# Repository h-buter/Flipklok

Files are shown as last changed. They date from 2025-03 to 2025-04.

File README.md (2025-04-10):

# Flipklok in 1970s Style with DCF77 Time Synchronization

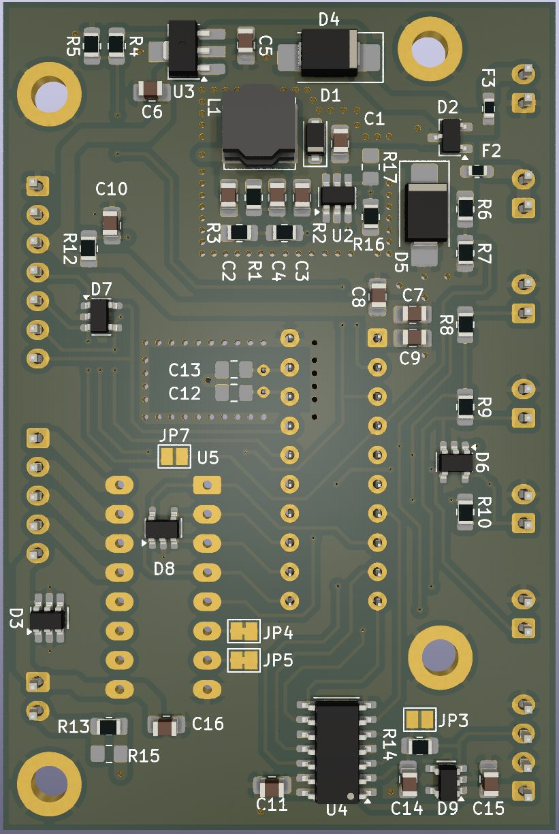
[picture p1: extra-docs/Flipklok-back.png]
back
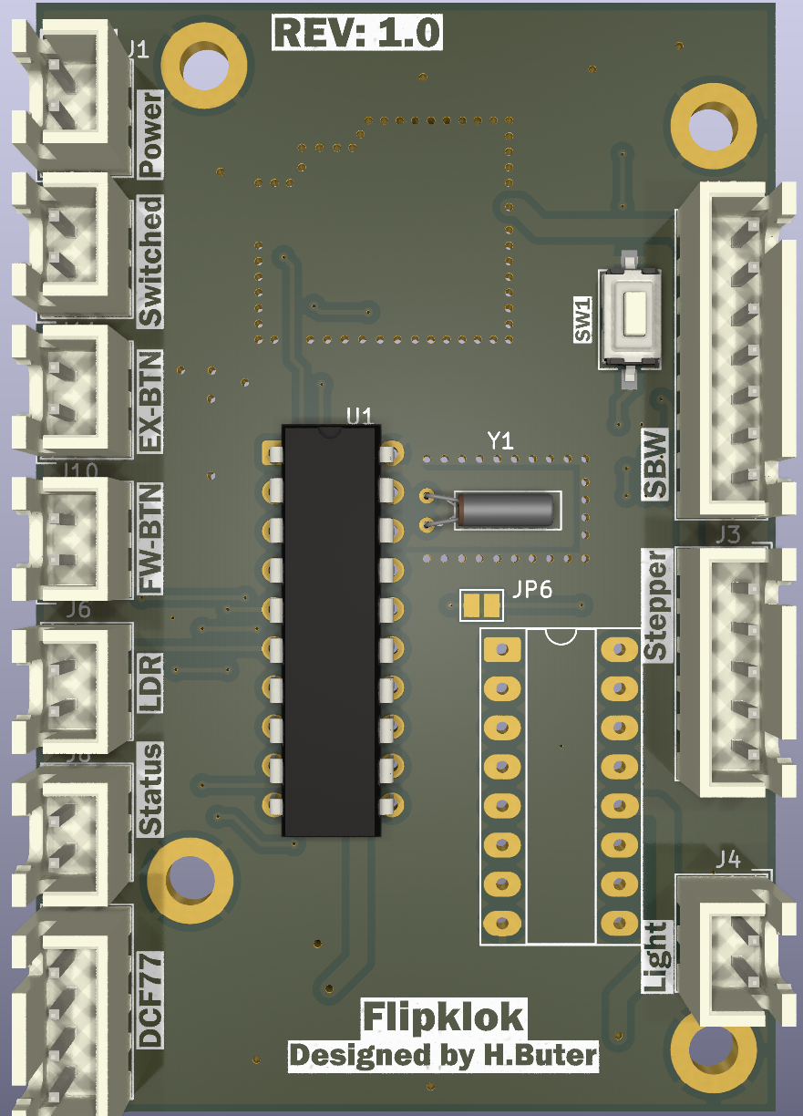
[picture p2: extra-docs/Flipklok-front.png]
front
|  |  |
|---|---|
| | |

Welcome to the repository for my project as part of my Bachelor's degree in Electronics at Windesheim. This
project involves creating a flip clock inspired by the design from the 1970s, which is synchronized using time
information from the DCF77 long-wave time signal. The goal is to ensure that this electronic and electromechanical
device operates efficiently within a low power environment.

At time of writing I am still deciding on if the clock will be used a desk clock or if I build it in to my 1977 Relaint Robin MK1
This is why some design decisions, like low power, are not always directly clear in the scope of a normal clock project.

For the complete documentation see the doxygen documentation hosted on GitHub pages:
- Index: https://h-buter.github.io/Flipklok/index.html
- Start of code: https://h-buter.github.io/Flipklok/main_8c.html 
- Interactive Bill of materials: https://h-buter.github.io/Flipklok/md_extra-docs_2bom.html

## Project Overview

This flip clock project integrates both mechanical components and electronics to display the current time
accurately based on data received from the DCF77 transmitter located in Germany. Designed with energy efficiency
in mind, the clock maintains continuous time tracking to compensate for any potential reception limitations of the
DCF77 signal while minimizing power consumption.

## Key Challenges

- **Mechanical and Time Management**: The project requires careful application of mechanics and efficient time
management techniques to ensure the device functions optimally on a 12V source.

- **Integration of Electronics and Electromechanics**: Incorporating electronic components like motors and sensors
for position detection into the mechanical design poses significant challenges.

- **PCB Design**: The creation of a custom PCB is necessary to accommodate all electronic components while
maintaining compactness and efficiency.

- **DCF77 Protocol Implementation**: Applying the DCF77 protocol ensures accurate time synchronization. This
involves handling signals and data correctly within the system’s constraints.

- **Software Development**: The software component, developed in C with some sections written in assembly
language, is responsible for processing DCF77 data and controlling stepper or servo motors to operate the flip
clock.

## Project Boundaries

### Software
The software aspect focuses on:
- Processing DCF77 signal data.
- Controlling a stepper/servo motor mechanism to display time changes accurately.

### Hardware
The hardware component involves:
- Integrating electronic and electromechanical components for seamless operation of the flip clock module.
- Receiving and processing DCF77 timing information effectively.

## Getting Started

To get started with this project, you need to:

- Code: 
    - If you want to view the code use the doxygen documentation (see intoduction) or view the source files on GitHub.
    - If you want to run the code, install TI code composer studio and clone this repository.
        - This repo should contain every file to be able to compile the code for the MSP430G2553
- PCB:
    - View the PCB files use the exported pdf: [exported pdf's](https://github.com/h-buter/Flipklok/tree/main/PCB/Flipklok/export)
    - Edit the PCB files, Kicad and clone the repo.
    - Run a production:
        - Download the gerber ZIP and give this to you're favorite PCB manufacturer, it may be possible the etch the board you're self but be warned this is not easy because of the multilayer construction.
        - Order the bom
        - Wait for everything to arrive 
        - Assemble
        - Test, don't let the make smoke out (not optional)
            - First power up test
            - Flash the code, i used a launchpad devboard see page 8 till 10 [link to datasheet of launchpad](https://www.ti.com/lit/ug/slau772a/slau772a.pdf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)
- Mechanics:
    - To view the 3d files you can use the free viewing program [Edrawings](https://www.edrawingsviewer.com/download-edrawings)
    - To edit the files you will need Solidworks

## Contribution

Contributions are welcome! Whether it's optimizing the code for better performance or suggesting improvements in
hardware integration, your input is valuable.

## License

This project is licensed under to be determined 

---

Thank you for exploring this unique blend of vintage design and electronics. Should you have any questions
or suggestions regarding this project, feel free to open an issue or contact me directly.

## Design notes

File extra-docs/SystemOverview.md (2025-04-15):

# System overview

This is the originally system overview where the schematic and PCB are based on:
System Overview

[Link to PDF version](SystemOverview.pdf)

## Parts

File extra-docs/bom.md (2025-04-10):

# Bill of materials

See link for an interactive BOM of the PCB:  
[Interactive BOM](https://h-buter.github.io/Flipklok/bom/Flipklok-1.0)

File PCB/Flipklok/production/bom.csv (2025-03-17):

Designator | Footprint | Quantity | Value | LCSC Part #
C1 | 0805 | 1 | 4.7uF 25V X5R
C10 | 0805 | 1 | 1nF
C11, C15, C16, C9 | 0805 | 4 | 0.1uF
C14 | 0805 | 1 | C
C2 | 0805 | 1 | 10uF 16V X5R
C3 | 0805 | 1 | 0,22uF
C4 | 0805 | 1 | 100pF
C5 | 0805 | 1 | 1uF 25V X7R
C6 | 0805 | 1 | 2.2uF 10V X7R
C7 | 0805 | 1 | 10uF
C8 | 0805 | 1 | 1uF
D1 | D_SOD-123F | 1 | PMEG3010ER 30V, 1A
D2 | TSOT-23 | 1 | ESDCAN01-2BLY
D3 | SOT-23-6_Handsoldering | 1 | ESDA19SC6
D4, D5 | D_SMB_Handsoldering | 2 | S2A 50V 1.5A
D6, D7, D8, D9 | SOT-23-5 | 4 | ESDA5V3SC5
F2, F3 | 0603 | 2 | Fuse
J1 | JST_XH_B2B-XH-A_1x02_P2.50mm_Vertical | 1 | Power
J10 | JST_XH_B2B-XH-A_1x02_P2.50mm_Vertical | 1 | FW-btn
J11 | JST_XH_B2B-XH-A_1x02_P2.50mm_Vertical | 1 | EX-btn
J12 | JST_XH_B7B-XH-A_1x07_P2.50mm_Vertical | 1 | Programheader
J2 | JST_XH_B2B-XH-A_1x02_P2.50mm_Vertical | 1 | SW
J3 | JST_XH_B5B-XH-A_1x05_P2.50mm_Vertical | 1 | 28BYJ-48
J4 | JST_XH_B2B-XH-A_1x02_P2.50mm_Vertical | 1 | Backlight
J5 | JST_XH_B4B-XH-A_1x04_P2.50mm_Vertical | 1 | DCF77
J6 | JST_XH_B2B-XH-A_1x02_P2.50mm_Vertical | 1 | LDR
J8 | JST_XH_B2B-XH-A_1x02_P2.50mm_Vertical | 1 | Indicator
L1 | L_Bourns_SRN6045TA | 1 | SRN6045HA
R1 | 0805 | 1 | 82k
R10, R16, R8, R9 | 0805 | 4 | 10k
R12 | 0805 | 1 | 47k
R13, R14, R4, R5, R6, R7 | 0805 | 6 | R
R2 | 0805 | 1 | 15k
R3 | 0805 | 1 | 500
RESET | SW_Tactile_SPST_NO_Straight_CK_PTS636Sx25SMTRLFS | 1 | Reset
U1 | DIP-20_W7.62mm | 1 | MSP430G2553IN20
U2 | SOT-23-6_Handsoldering | 1 | ~
U3 | SOT-89-3_Handsoldering | 1 | AP2205
U4 | SOIC-14_3.9x8.7mm_P1.27mm | 1 | 74HC00
U5 | DIP-16_W7.62mm_Socket_LongPads | 1 | ULQ2003A
Y1 | Crystal_C26-LF_D2.1mm_L6.5mm_Horizontal | 1 | ECS-.327-6-13X

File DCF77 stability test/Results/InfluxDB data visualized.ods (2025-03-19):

name | tags | time epoch | time | device | differenceNtpDcf | errorRate | receiveErrors | timeErrors | timeSuccessful | totalDcfMessages
Mon Mar 10 15:37:57 2025 |  | 1,74E+18 | 10-03-2025 14:38 | Flipklok |  |  | 0
Mon Mar 10 15:37:57 2025 |  | 1,74161752526132E+018 | 10-03-2025 14:38 | Flipklok |  |  |  | 0
Mon Mar 10 15:37:57 2025 |  | 1,74161752531512E+018 | 10-03-2025 14:38 | Flipklok |  |  |  |  | 0
Mon Mar 10 15:37:57 2025 |  | 1,74161752536813E+018 | 10-03-2025 14:38 | Flipklok |  |  |  |  |  | 0
Mon Mar 10 15:37:57 2025 |  | 1,74161752541951E+018 | 10-03-2025 14:38 | Flipklok | 0
Mon Mar 10 15:37:57 2025 |  | 1,74161752546433E+018 | 10-03-2025 14:38 | Flipklok |  | 0 |  |  |  |  | Error rate is the percentage off the succesfull received DCF time messages which differ less then 2 minutes from NTP compared to the total DCF messages the receiver should have received. Total messages is calculated based on the passed time since starting receiving times the DCF messages per minute (1 message)
Mon Mar 10 15:37:57 2025 |  | 1,74161759834028E+018 | 10-03-2025 14:39 | Flipklok |  |  | 0
Mon Mar 10 15:37:57 2025 |  | 1,74161759839459E+018 | 10-03-2025 14:39 | Flipklok |  |  |  | 0
Mon Mar 10 15:37:57 2025 |  | 1,74161759844223E+018 | 10-03-2025 14:39 | Flipklok |  |  |  |  | 1
Mon Mar 10 15:37:57 2025 |  | 1,74161759852017E+018 | 10-03-2025 14:39 | Flipklok |  |  |  |  |  | 1
Mon Mar 10 15:37:57 2025 |  | 1,74161759858386E+018 | 10-03-2025 14:39 | Flipklok | 1
Mon Mar 10 15:37:57 2025 |  | 1,74161759863161E+018 | 10-03-2025 14:39 | Flipklok |  | 100
Mon Mar 10 15:37:57 2025 |  | 1,74161771833652E+018 | 10-03-2025 14:41 | Flipklok |  |  | 0
Mon Mar 10 15:37:57 2025 |  | 1,74161771838582E+018 | 10-03-2025 14:41 | Flipklok |  |  |  | 0
Mon Mar 10 15:37:57 2025 |  | 1,74161771842713E+018 | 10-03-2025 14:41 | Flipklok |  |  |  |  | 2
Mon Mar 10 15:37:57 2025 |  | 1,74161771848856E+018 | 10-03-2025 14:41 | Flipklok |  |  |  |  |  | 2
Mon Mar 10 15:37:57 2025 |  | 1,7416177185482E+018 | 10-03-2025 14:41 | Flipklok | 1
Mon Mar 10 15:37:57 2025 |  | 1,74161771863362E+018 | 10-03-2025 14:41 | Flipklok |  | 66
Mon Mar 10 15:37:57 2025 |  | 1,74161783833777E+018 | 10-03-2025 14:43 | Flipklok |  |  | 0
Mon Mar 10 15:37:57 2025 |  | 1,74161783839286E+018 | 10-03-2025 14:43 | Flipklok |  |  |  | 0
Mon Mar 10 15:37:57 2025 |  | 1,7416178384474E+018 | 10-03-2025 14:43 | Flipklok |  |  |  |  | 3
Mon Mar 10 15:37:57 2025 |  | 1,74161783850445E+018 | 10-03-2025 14:43 | Flipklok |  |  |  |  |  | 3
Mon Mar 10 15:37:57 2025 |  | 1,74161783854783E+018 | 10-03-2025 14:43 | Flipklok | 1
Mon Mar 10 15:37:57 2025 |  | 1,74161783859635E+018 | 10-03-2025 14:43 | Flipklok |  | 60
Mon Mar 10 15:37:57 2025 |  | 1,7416179583394E+018 | 10-03-2025 14:45 | Flipklok |  |  | 0
Mon Mar 10 15:37:57 2025 |  | 1,74161795838037E+018 | 10-03-2025 14:45 | Flipklok |  |  |  | 0
Mon Mar 10 15:37:57 2025 |  | 1,74161795841564E+018 | 10-03-2025 14:45 | Flipklok |  |  |  |  | 4
Mon Mar 10 15:37:57 2025 |  | 1,74161795848212E+018 | 10-03-2025 14:45 | Flipklok |  |  |  |  |  | 4
Mon Mar 10 15:37:57 2025 |  | 1,74161795851829E+018 | 10-03-2025 14:45 | Flipklok | 1
Mon Mar 10 15:37:57 2025 |  | 1,74161795857532E+018 | 10-03-2025 14:45 | Flipklok |  | 57
Mon Mar 10 15:37:57 2025 |  | 1,74161797997156E+018 | 10-03-2025 14:46 | Flipklok |  |  | 0
Mon Mar 10 15:37:57 2025 |  | 1,74161798001288E+018 | 10-03-2025 14:46 | Flipklok |  |  |  | 0
Mon Mar 10 15:37:57 2025 |  | 1,74161798006991E+018 | 10-03-2025 14:46 | Flipklok |  |  |  |  | 0
Mon Mar 10 15:37:57 2025 |  | 1,74161798011943E+018 | 10-03-2025 14:46 | Flipklok |  |  |  |  |  | 0
Mon Mar 10 15:37:57 2025 |  | 1,74161798017878E+018 | 10-03-2025 14:46 | Flipklok | 0
Mon Mar 10 15:37:57 2025 |  | 1,74161798022801E+018 | 10-03-2025 14:46 | Flipklok |  | 0
Mon Mar 10 15:37:57 2025 |  | 1,74161807833787E+018 | 10-03-2025 14:47 | Flipklok |  |  | 0
Mon Mar 10 15:37:57 2025 |  | 1,74161807837886E+018 | 10-03-2025 14:47 | Flipklok |  |  |  | 0
Mon Mar 10 15:37:57 2025 |  | 1,74161807842588E+018 | 10-03-2025 14:47 | Flipklok |  |  |  |  | 1
Mon Mar 10 15:37:57 2025 |  | 1,74161807846573E+018 | 10-03-2025 14:47 | Flipklok |  |  |  |  |  | 1
Mon Mar 10 15:37:57 2025 |  | 1,74161807851028E+018 | 10-03-2025 14:47 | Flipklok | 1
Mon Mar 10 15:37:57 2025 |  | 1,74161807854803E+018 | 10-03-2025 14:47 | Flipklok |  | 100
Mon Mar 10 15:37:57 2025 |  | 1,74161819836401E+018 | 10-03-2025 14:49 | Flipklok |  |  | 0
Mon Mar 10 15:37:57 2025 |  | 1,74161819841384E+018 | 10-03-2025 14:49 | Flipklok |  |  |  | 0
Mon Mar 10 15:37:57 2025 |  | 1,74161819846113E+018 | 10-03-2025 14:49 | Flipklok |  |  |  |  | 2
Mon Mar 10 15:37:57 2025 |  | 1,74161819850314E+018 | 10-03-2025 14:49 | Flipklok |  |  |  |  |  | 2
Mon Mar 10 15:37:57 2025 |  | 1,74161819854774E+018 | 10-03-2025 14:49 | Flipklok | 1
Mon Mar 10 15:37:57 2025 |  | 1,74161819858221E+018 | 10-03-2025 14:49 | Flipklok |  | 66
Mon Mar 10 15:37:57 2025 |  | 1,74161831834267E+018 | 10-03-2025 14:51 | Flipklok |  |  | 0
Mon Mar 10 15:37:57 2025 |  | 1,74161831840253E+018 | 10-03-2025 14:51 | Flipklok |  |  |  | 0
Mon Mar 10 15:37:57 2025 |  | 1,74161831845447E+018 | 10-03-2025 14:51 | Flipklok |  |  |  |  | 3
Mon Mar 10 15:37:57 2025 |  | 1,74161831850987E+018 | 10-03-2025 14:51 | Flipklok |  |  |  |  |  | 3
Mon Mar 10 15:37:57 2025 |  | 1,74161831855421E+018 | 10-03-2025 14:51 | Flipklok | 1
Mon Mar 10 15:37:57 2025 |  | 1,74161831861261E+018 | 10-03-2025 14:51 | Flipklok |  | 60
Mon Mar 10 15:37:57 2025 |  | 1,7416184383409E+018 | 10-03-2025 14:53 | Flipklok |  |  | 0
Mon Mar 10 15:37:57 2025 |  | 1,74161843838276E+018 | 10-03-2025 14:53 | Flipklok |  |  |  | 0
Mon Mar 10 15:37:57 2025 |  | 1,74161843843765E+018 | 10-03-2025 14:53 | Flipklok |  |  |  |  | 4
Mon Mar 10 15:37:57 2025 |  | 1,74161843848035E+018 | 10-03-2025 14:53 | Flipklok |  |  |  |  |  | 4
Mon Mar 10 15:37:57 2025 |  | 1,74161843852688E+018 | 10-03-2025 14:53 | Flipklok | 1
Mon Mar 10 15:37:57 2025 |  | 1,74161843856549E+018 | 10-03-2025 14:53 | Flipklok |  | 57
Mon Mar 10 15:37:57 2025 |  | 1,74161855833229E+018 | 10-03-2025 14:55 | Flipklok |  |  | 0
Mon Mar 10 15:37:57 2025 |  | 1,7416185583764E+018 | 10-03-2025 14:55 | Flipklok |  |  |  | 0
Mon Mar 10 15:37:57 2025 |  | 1,74161855841717E+018 | 10-03-2025 14:55 | Flipklok |  |  |  |  | 5
Mon Mar 10 15:37:57 2025 |  | 1,74161855847291E+018 | 10-03-2025 14:55 | Flipklok |  |  |  |  |  | 5
Mon Mar 10 15:37:57 2025 |  | 1,74161855851251E+018 | 10-03-2025 14:55 | Flipklok | 1
Mon Mar 10 15:37:57 2025 |  | 1,74161855857643E+018 | 10-03-2025 14:55 | Flipklok |  | 55
Mon Mar 10 15:37:57 2025 |  | 1,74161867834202E+018 | 10-03-2025 14:57 | Flipklok |  |  | 0
Mon Mar 10 15:37:57 2025 |  | 1,74161867838452E+018 | 10-03-2025 14:57 | Flipklok |  |  |  | 0
Mon Mar 10 15:37:57 2025 |  | 1,74161867842892E+018 | 10-03-2025 14:57 | Flipklok |  |  |  |  | 6
Mon Mar 10 15:37:57 2025 |  | 1,74161867847274E+018 | 10-03-2025 14:57 | Flipklok |  |  |  |  |  | 6
Mon Mar 10 15:37:57 2025 |  | 1,74161867853394E+018 | 10-03-2025 14:57 | Flipklok | 1
Mon Mar 10 15:37:57 2025 |  | 1,74161867857158E+018 | 10-03-2025 14:57 | Flipklok |  | 54
Mon Mar 10 15:37:57 2025 |  | 1,74161879835881E+018 | 10-03-2025 14:59 | Flipklok |  |  | 0
Mon Mar 10 15:37:57 2025 |  | 1,74161879840795E+018 | 10-03-2025 14:59 | Flipklok |  |  |  | 0
Mon Mar 10 15:37:57 2025 |  | 1,74161879845343E+018 | 10-03-2025 14:59 | Flipklok |  |  |  |  | 7
Mon Mar 10 15:37:57 2025 |  | 1,74161879850737E+018 | 10-03-2025 14:59 | Flipklok |  |  |  |  |  | 7
Mon Mar 10 15:37:57 2025 |  | 1,74161879855845E+018 | 10-03-2025 14:59 | Flipklok | 1
Mon Mar 10 15:37:57 2025 |  | 1,74161879861476E+018 | 10-03-2025 14:59 | Flipklok |  | 53
Mon Mar 10 15:37:57 2025 |  | 1,74161891834477E+018 | 10-03-2025 15:01 | Flipklok |  |  | 0
Mon Mar 10 15:37:57 2025 |  | 1,74161891839844E+018 | 10-03-2025 15:01 | Flipklok |  |  |  | 0
Mon Mar 10 15:37:57 2025 |  | 1,74161891845379E+018 | 10-03-2025 15:01 | Flipklok |  |  |  |  | 8
Mon Mar 10 15:37:57 2025 |  | 1,74161891850913E+018 | 10-03-2025 15:01 | Flipklok |  |  |  |  |  | 8
Mon Mar 10 15:37:57 2025 |  | 1,74161891854995E+018 | 10-03-2025 15:01 | Flipklok | 1
Mon Mar 10 15:37:57 2025 |  | 1,74161891859917E+018 | 10-03-2025 15:01 | Flipklok |  | 53
Mon Mar 10 15:37:57 2025 |  | 1,74161903833841E+018 | 10-03-2025 15:03 | Flipklok |  |  | 0
Mon Mar 10 15:37:57 2025 |  | 1,74161903838229E+018 | 10-03-2025 15:03 | Flipklok |  |  |  | 0
Mon Mar 10 15:37:57 2025 |  | 1,74161903842902E+018 | 10-03-2025 15:03 | Flipklok |  |  |  |  | 9
Mon Mar 10 15:37:57 2025 |  | 1,74161903846867E+018 | 10-03-2025 15:03 | Flipklok |  |  |  |  |  | 9
Mon Mar 10 15:37:57 2025 |  | 1,74161903851465E+018 | 10-03-2025 15:03 | Flipklok | 1
Mon Mar 10 15:37:57 2025 |  | 1,74161903855614E+018 | 10-03-2025 15:03 | Flipklok |  | 52
Mon Mar 10 15:37:57 2025 |  | 1,74161915834689E+018 | 10-03-2025 15:05 | Flipklok |  |  | 0
Mon Mar 10 15:37:57 2025 |  | 1,74161915838733E+018 | 10-03-2025 15:05 | Flipklok |  |  |  | 0
Mon Mar 10 15:37:57 2025 |  | 1,74161915842577E+018 | 10-03-2025 15:05 | Flipklok |  |  |  |  | 10
Mon Mar 10 15:37:57 2025 |  | 1,74161915847662E+018 | 10-03-2025 15:05 | Flipklok |  |  |  |  |  | 10
Mon Mar 10 15:37:57 2025 |  | 1,74161915852519E+018 | 10-03-2025 15:05 | Flipklok | 1
Mon Mar 10 15:37:57 2025 |  | 1,74161915857063E+018 | 10-03-2025 15:05 | Flipklok |  | 52
Mon Mar 10 15:37:57 2025 |  | 1,74161927834013E+018 | 10-03-2025 15:07 | Flipklok |  |  | 0
Mon Mar 10 15:37:57 2025 |  | 1,74161927838911E+018 | 10-03-2025 15:07 | Flipklok |  |  |  | 0
Mon Mar 10 15:37:57 2025 |  | 1,74161927844475E+018 | 10-03-2025 15:07 | Flipklok |  |  |  |  | 11
Mon Mar 10 15:37:57 2025 |  | 1,74161927849178E+018 | 10-03-2025 15:07 | Flipklok |  |  |  |  |  | 11
Mon Mar 10 15:37:57 2025 |  | 1,74161927853523E+018 | 10-03-2025 15:07 | Flipklok | 1
Mon Mar 10 15:37:57 2025 |  | 1,74161927856935E+018 | 10-03-2025 15:07 | Flipklok |  | 52
Mon Mar 10 15:37:57 2025 |  | 1,74161939834758E+018 | 10-03-2025 15:09 | Flipklok |  |  | 0
Mon Mar 10 15:37:57 2025 |  | 1,74161939840016E+018 | 10-03-2025 15:09 | Flipklok |  |  |  | 0
Mon Mar 10 15:37:57 2025 |  | 1,74161939845001E+018 | 10-03-2025 15:09 | Flipklok |  |  |  |  | 12
Mon Mar 10 15:37:57 2025 |  | 1,74161939849862E+018 | 10-03-2025 15:09 | Flipklok |  |  |  |  |  | 12
Mon Mar 10 15:37:57 2025 |  | 1,74161939854705E+018 | 10-03-2025 15:09 | Flipklok | 1
Mon Mar 10 15:37:57 2025 |  | 1,74161939859266E+018 | 10-03-2025 15:09 | Flipklok |  | 52
Mon Mar 10 15:37:57 2025 |  | 1,74161951835821E+018 | 10-03-2025 15:11 | Flipklok |  |  | 0
Mon Mar 10 15:37:57 2025 |  | 1,7416195184014E+018 | 10-03-2025 15:11 | Flipklok |  |  |  | 0
Mon Mar 10 15:37:57 2025 |  | 1,74161951845847E+018 | 10-03-2025 15:11 | Flipklok |  |  |  |  | 13
Mon Mar 10 15:37:57 2025 |  | 1,74161951850843E+018 | 10-03-2025 15:11 | Flipklok |  |  |  |  |  | 13
Mon Mar 10 15:37:57 2025 |  | 1,74161951856264E+018 | 10-03-2025 15:11 | Flipklok | 1
Mon Mar 10 15:37:57 2025 |  | 1,74161951860501E+018 | 10-03-2025 15:11 | Flipklok |  | 52
Mon Mar 10 15:37:57 2025 |  | 1,74161963835167E+018 | 10-03-2025 15:13 | Flipklok |  |  | 0
Mon Mar 10 15:37:57 2025 |  | 1,74161963840503E+018 | 10-03-2025 15:13 | Flipklok |  |  |  | 0
Mon Mar 10 15:37:57 2025 |  | 1,74161963846286E+018 | 10-03-2025 15:13 | Flipklok |  |  |  |  | 14
Mon Mar 10 15:37:57 2025 |  | 1,74161963850622E+018 | 10-03-2025 15:13 | Flipklok |  |  |  |  |  | 14
Mon Mar 10 15:37:57 2025 |  | 1,7416196385562E+018 | 10-03-2025 15:13 | Flipklok | 1
Mon Mar 10 15:37:57 2025 |  | 1,74161963861275E+018 | 10-03-2025 15:13 | Flipklok |  | 51
Mon Mar 10 15:37:57 2025 |  | 1,74161975834011E+018 | 10-03-2025 15:15 | Flipklok |  |  | 0
Mon Mar 10 15:37:57 2025 |  | 1,74161975838675E+018 | 10-03-2025 15:15 | Flipklok |  |  |  | 0
Mon Mar 10 15:37:57 2025 |  | 1,7416197584358E+018 | 10-03-2025 15:15 | Flipklok |  |  |  |  | 15
Mon Mar 10 15:37:57 2025 |  | 1,74161975847544E+018 | 10-03-2025 15:15 | Flipklok |  |  |  |  |  | 15
Mon Mar 10 15:37:57 2025 |  | 1,74161975851756E+018 | 10-03-2025 15:15 | Flipklok | 1
Mon Mar 10 15:37:57 2025 |  | 1,74161975855764E+018 | 10-03-2025 15:15 | Flipklok |  | 51
Mon Mar 10 15:37:57 2025 |  | 1,741619878364E+018 | 10-03-2025 15:17 | Flipklok |  |  | 0
Mon Mar 10 15:37:57 2025 |  | 1,74161987840267E+018 | 10-03-2025 15:17 | Flipklok |  |  |  | 0
Mon Mar 10 15:37:57 2025 |  | 1,74161987847716E+018 | 10-03-2025 15:17 | Flipklok |  |  |  |  | 16
Mon Mar 10 15:37:57 2025 |  | 1,74161987851769E+018 | 10-03-2025 15:17 | Flipklok |  |  |  |  |  | 16
Mon Mar 10 15:37:57 2025 |  | 1,74161987855523E+018 | 10-03-2025 15:17 | Flipklok | 1
Mon Mar 10 15:37:57 2025 |  | 1,74161987861208E+018 | 10-03-2025 15:17 | Flipklok |  | 51
Mon Mar 10 15:37:57 2025 |  | 1,74161999835218E+018 | 10-03-2025 15:19 | Flipklok |  |  | 0
Mon Mar 10 15:37:57 2025 |  | 1,74161999842673E+018 | 10-03-2025 15:19 | Flipklok |  |  |  | 0
Mon Mar 10 15:37:57 2025 |  | 1,74161999847287E+018 | 10-03-2025 15:19 | Flipklok |  |  |  |  | 17
Mon Mar 10 15:37:57 2025 |  | 1,74161999853226E+018 | 10-03-2025 15:19 | Flipklok |  |  |  |  |  | 17
Mon Mar 10 15:37:57 2025 |  | 1,74161999856654E+018 | 10-03-2025 15:19 | Flipklok | 1
Mon Mar 10 15:37:57 2025 |  | 1,74161999861699E+018 | 10-03-2025 15:19 | Flipklok |  | 51
Mon Mar 10 15:37:57 2025 |  | 1,74162011835526E+018 | 10-03-2025 15:21 | Flipklok |  |  | 0
Mon Mar 10 15:37:57 2025 |  | 1,7416201184086E+018 | 10-03-2025 15:21 | Flipklok |  |  |  | 0
Mon Mar 10 15:37:57 2025 |  | 1,74162011847135E+018 | 10-03-2025 15:21 | Flipklok |  |  |  |  | 18
Mon Mar 10 15:37:57 2025 |  | 1,74162011852169E+018 | 10-03-2025 15:21 | Flipklok |  |  |  |  |  | 18
Mon Mar 10 15:37:57 2025 |  | 1,74162011856512E+018 | 10-03-2025 15:21 | Flipklok | 1
Mon Mar 10 15:37:57 2025 |  | 1,74162011860589E+018 | 10-03-2025 15:21 | Flipklok |  | 51
Mon Mar 10 15:37:57 2025 |  | 1,74162023834604E+018 | 10-03-2025 15:23 | Flipklok |  |  | 0
Mon Mar 10 15:37:57 2025 |  | 1,74162023839694E+018 | 10-03-2025 15:23 | Flipklok |  |  |  | 0
Mon Mar 10 15:37:57 2025 |  | 1,74162023843456E+018 | 10-03-2025 15:23 | Flipklok |  |  |  |  | 19
Mon Mar 10 15:37:57 2025 |  | 1,74162023849875E+018 | 10-03-2025 15:23 | Flipklok |  |  |  |  |  | 19
Mon Mar 10 15:37:57 2025 |  | 1,74162023854677E+018 | 10-03-2025 15:23 | Flipklok | 1
Mon Mar 10 15:37:57 2025 |  | 1,74162023860737E+018 | 10-03-2025 15:23 | Flipklok |  | 51
Mon Mar 10 15:37:57 2025 |  | 1,74162035833753E+018 | 10-03-2025 15:25 | Flipklok |  |  | 0
Mon Mar 10 15:37:57 2025 |  | 1,74162035837474E+018 | 10-03-2025 15:25 | Flipklok |  |  |  | 0
Mon Mar 10 15:37:57 2025 |  | 1,74162035842052E+018 | 10-03-2025 15:25 | Flipklok |  |  |  |  | 20
Mon Mar 10 15:37:57 2025 |  | 1,74162035845851E+018 | 10-03-2025 15:25 | Flipklok |  |  |  |  |  | 20
Mon Mar 10 15:37:57 2025 |  | 1,74162035849784E+018 | 10-03-2025 15:25 | Flipklok | 1
Mon Mar 10 15:37:57 2025 |  | 1,74162035854944E+018 | 10-03-2025 15:25 | Flipklok |  | 51
Mon Mar 10 15:37:57 2025 |  | 1,74162047833673E+018 | 10-03-2025 15:27 | Flipklok |  |  | 0
Mon Mar 10 15:37:57 2025 |  | 1,7416204783943E+018 | 10-03-2025 15:27 | Flipklok |  |  |  | 0
Mon Mar 10 15:37:57 2025 |  | 1,74162047842495E+018 | 10-03-2025 15:27 | Flipklok |  |  |  |  | 21
Mon Mar 10 15:37:57 2025 |  | 1,74162047846562E+018 | 10-03-2025 15:27 | Flipklok |  |  |  |  |  | 21
Mon Mar 10 15:37:57 2025 |  | 1,74162047849833E+018 | 10-03-2025 15:27 | Flipklok | 1
Mon Mar 10 15:37:57 2025 |  | 1,74162047855493E+018 | 10-03-2025 15:27 | Flipklok |  | 51
Mon Mar 10 15:37:57 2025 |  | 1,74162059834838E+018 | 10-03-2025 15:29 | Flipklok |  |  | 0
Mon Mar 10 15:37:57 2025 |  | 1,74162059841207E+018 | 10-03-2025 15:29 | Flipklok |  |  |  | 0
Mon Mar 10 15:37:57 2025 |  | 1,74162059845885E+018 | 10-03-2025 15:29 | Flipklok |  |  |  |  | 22
Mon Mar 10 15:37:57 2025 |  | 1,74162059851288E+018 | 10-03-2025 15:29 | Flipklok |  |  |  |  |  | 22
Mon Mar 10 15:37:57 2025 |  | 1,74162059854669E+018 | 10-03-2025 15:29 | Flipklok | 1
Mon Mar 10 15:37:57 2025 |  | 1,74162059859997E+018 | 10-03-2025 15:29 | Flipklok |  | 51
Mon Mar 10 15:37:57 2025 |  | 1,74162071835214E+018 | 10-03-2025 15:31 | Flipklok |  |  | 0
Mon Mar 10 15:37:57 2025 |  | 1,74162071839539E+018 | 10-03-2025 15:31 | Flipklok |  |  |  | 0
Mon Mar 10 15:37:57 2025 |  | 1,74162071843296E+018 | 10-03-2025 15:31 | Flipklok |  |  |  |  | 23
Mon Mar 10 15:37:57 2025 |  | 1,74162071849511E+018 | 10-03-2025 15:31 | Flipklok |  |  |  |  |  | 23
Mon Mar 10 15:37:57 2025 |  | 1,74162071856378E+018 | 10-03-2025 15:31 | Flipklok | 1
Mon Mar 10 15:37:57 2025 |  | 1,74162071863693E+018 | 10-03-2025 15:31 | Flipklok |  | 51
Mon Mar 10 15:37:57 2025 |  | 1,74162083834144E+018 | 10-03-2025 15:33 | Flipklok |  |  | 0
Mon Mar 10 15:37:57 2025 |  | 1,74162083838846E+018 | 10-03-2025 15:33 | Flipklok |  |  |  | 0
Mon Mar 10 15:37:57 2025 |  | 1,74162083844679E+018 | 10-03-2025 15:33 | Flipklok |  |  |  |  | 24
Mon Mar 10 15:37:57 2025 |  | 1,74162083848548E+018 | 10-03-2025 15:33 | Flipklok |  |  |  |  |  | 24
Mon Mar 10 15:37:57 2025 |  | 1,74162083855208E+018 | 10-03-2025 15:33 | Flipklok | 1
Mon Mar 10 15:37:57 2025 |  | 1,74162083864225E+018 | 10-03-2025 15:33 | Flipklok |  | 51
Mon Mar 10 15:37:57 2025 |  | 1,7416209583425E+018 | 10-03-2025 15:35 | Flipklok |  |  | 0
Mon Mar 10 15:37:57 2025 |  | 1,74162095838206E+018 | 10-03-2025 15:35 | Flipklok |  |  |  | 0
Mon Mar 10 15:37:57 2025 |  | 1,74162095843079E+018 | 10-03-2025 15:35 | Flipklok |  |  |  |  | 25
Mon Mar 10 15:37:57 2025 |  | 1,74162095847239E+018 | 10-03-2025 15:35 | Flipklok |  |  |  |  |  | 25
Mon Mar 10 15:37:57 2025 |  | 1,74162095851513E+018 | 10-03-2025 15:35 | Flipklok | 1
Mon Mar 10 15:37:57 2025 |  | 1,74162095855708E+018 | 10-03-2025 15:35 | Flipklok |  | 51
Mon Mar 10 15:37:57 2025 |  | 1,74162107836443E+018 | 10-03-2025 15:37 | Flipklok |  |  | 0
Mon Mar 10 15:37:57 2025 |  | 1,74162107841763E+018 | 10-03-2025 15:37 | Flipklok |  |  |  | 0
Mon Mar 10 15:37:57 2025 |  | 1,74162107847033E+018 | 10-03-2025 15:37 | Flipklok |  |  |  |  | 26
Mon Mar 10 15:37:57 2025 |  | 1,74162107850489E+018 | 10-03-2025 15:37 | Flipklok |  |  |  |  |  | 26
Mon Mar 10 15:37:57 2025 |  | 1,7416210785615E+018 | 10-03-2025 15:37 | Flipklok | 1
Mon Mar 10 15:37:57 2025 |  | 1,74162107861078E+018 | 10-03-2025 15:37 | Flipklok |  | 50
Mon Mar 10 15:37:57 2025 |  | 1,74162119837258E+018 | 10-03-2025 15:39 | Flipklok |  |  | 0
Mon Mar 10 15:37:57 2025 |  | 1,74162119842131E+018 | 10-03-2025 15:39 | Flipklok |  |  |  | 0
Mon Mar 10 15:37:57 2025 |  | 1,74162119849083E+018 | 10-03-2025 15:39 | Flipklok |  |  |  |  | 27
Mon Mar 10 15:37:57 2025 |  | 1,74162119854067E+018 | 10-03-2025 15:39 | Flipklok |  |  |  |  |  | 27
Mon Mar 10 15:37:57 2025 |  | 1,74162119859029E+018 | 10-03-2025 15:39 | Flipklok | 1
Mon Mar 10 15:37:57 2025 |  | 1,74162119864088E+018 | 10-03-2025 15:39 | Flipklok |  | 50
Mon Mar 10 15:37:57 2025 |  | 1,74162131835431E+018 | 10-03-2025 15:41 | Flipklok |  |  | 0
Mon Mar 10 15:37:57 2025 |  | 1,74162131842422E+018 | 10-03-2025 15:41 | Flipklok |  |  |  | 0
Mon Mar 10 15:37:57 2025 |  | 1,74162131849697E+018 | 10-03-2025 15:41 | Flipklok |  |  |  |  | 28
Mon Mar 10 15:37:57 2025 |  | 1,74162131855216E+018 | 10-03-2025 15:41 | Flipklok |  |  |  |  |  | 28
Mon Mar 10 15:37:57 2025 |  | 1,74162131860099E+018 | 10-03-2025 15:41 | Flipklok | 1
Mon Mar 10 15:37:57 2025 |  | 1,74162131864943E+018 | 10-03-2025 15:41 | Flipklok |  | 50
Mon Mar 10 15:37:57 2025 |  | 1,7416214383452E+018 | 10-03-2025 15:43 | Flipklok |  |  | 0
Mon Mar 10 15:37:57 2025 |  | 1,74162143838614E+018 | 10-03-2025 15:43 | Flipklok |  |  |  | 0
Mon Mar 10 15:37:57 2025 |  | 1,74162143842934E+018 | 10-03-2025 15:43 | Flipklok |  |  |  |  | 29
Mon Mar 10 15:37:57 2025 |  | 1,74162143848645E+018 | 10-03-2025 15:43 | Flipklok |  |  |  |  |  | 29
Mon Mar 10 15:37:57 2025 |  | 1,74162143852846E+018 | 10-03-2025 15:43 | Flipklok | 1
Mon Mar 10 15:37:57 2025 |  | 1,74162143858905E+018 | 10-03-2025 15:43 | Flipklok |  | 50
Mon Mar 10 15:37:57 2025 |  | 1,74162155833011E+018 | 10-03-2025 15:45 | Flipklok |  |  | 0
Mon Mar 10 15:37:57 2025 |  | 1,74162155839481E+018 | 10-03-2025 15:45 | Flipklok |  |  |  | 0
Mon Mar 10 15:37:57 2025 |  | 1,74162155843738E+018 | 10-03-2025 15:45 | Flipklok |  |  |  |  | 30
Mon Mar 10 15:37:57 2025 |  | 1,74162155848648E+018 | 10-03-2025 15:45 | Flipklok |  |  |  |  |  | 30
Mon Mar 10 15:37:57 2025 |  | 1,74162155852556E+018 | 10-03-2025 15:45 | Flipklok | 1
Mon Mar 10 15:37:57 2025 |  | 1,74162155855958E+018 | 10-03-2025 15:45 | Flipklok |  | 50
Mon Mar 10 15:37:57 2025 |  | 1,74162168559473E+018 | 10-03-2025 15:48 | Flipklok |  |  | 0
Mon Mar 10 15:37:57 2025 |  | 1,74162168563144E+018 | 10-03-2025 15:48 | Flipklok |  |  |  | 0
Mon Mar 10 15:37:57 2025 |  | 1,7416216856806E+018 | 10-03-2025 15:48 | Flipklok |  |  |  |  | 0
Mon Mar 10 15:37:57 2025 |  | 1,74162168573604E+018 | 10-03-2025 15:48 | Flipklok |  |  |  |  |  | 0
Mon Mar 10 15:37:57 2025 |  | 1,74162168579947E+018 | 10-03-2025 15:48 | Flipklok | 0
Mon Mar 10 15:37:57 2025 |  | 1,74162168584974E+018 | 10-03-2025 15:48 | Flipklok |  | 0
Mon Mar 10 15:37:57 2025 |  | 1,74162178425137E+018 | 10-03-2025 15:49 | Flipklok |  |  | 1
Mon Mar 10 15:37:57 2025 |  | 1,74162178429601E+018 | 10-03-2025 15:49 | Flipklok |  |  |  | 0
Mon Mar 10 15:37:57 2025 |  | 1,74162178434705E+018 | 10-03-2025 15:49 | Flipklok |  |  |  |  | 0
Mon Mar 10 15:37:57 2025 |  | 1,74162178438428E+018 | 10-03-2025 15:49 | Flipklok |  |  |  |  |  | 1
Mon Mar 10 15:37:57 2025 |  | 1,74162178442517E+018 | 10-03-2025 15:49 | Flipklok | 0
Mon Mar 10 15:37:57 2025 |  | 1,74162178447693E+018 | 10-03-2025 15:49 | Flipklok |  | 0
Mon Mar 10 15:37:57 2025 |  | 1,74162191835495E+018 | 10-03-2025 15:51 | Flipklok |  |  | 1
Mon Mar 10 15:37:57 2025 |  | 1,74162191840963E+018 | 10-03-2025 15:51 | Flipklok |  |  |  | 0
Mon Mar 10 15:37:57 2025 |  | 1,74162191844757E+018 | 10-03-2025 15:51 | Flipklok |  |  |  |  | 1
Mon Mar 10 15:37:57 2025 |  | 1,7416219185013E+018 | 10-03-2025 15:51 | Flipklok |  |  |  |  |  | 2
Mon Mar 10 15:37:57 2025 |  | 1,74162191854824E+018 | 10-03-2025 15:51 | Flipklok | 1
Mon Mar 10 15:37:57 2025 |  | 1,74162191859468E+018 | 10-03-2025 15:51 | Flipklok |  | 33
Mon Mar 10 15:37:57 2025 |  | 1,74162203836602E+018 | 10-03-2025 15:53 | Flipklok |  |  | 1
Mon Mar 10 15:37:57 2025 |  | 1,74162203843232E+018 | 10-03-2025 15:53 | Flipklok |  |  |  | 0
Mon Mar 10 15:37:57 2025 |  | 1,74162203847778E+018 | 10-03-2025 15:53 | Flipklok |  |  |  |  | 2
Mon Mar 10 15:37:57 2025 |  | 1,74162203851477E+018 | 10-03-2025 15:53 | Flipklok |  |  |  |  |  | 3
Mon Mar 10 15:37:57 2025 |  | 1,74162203858394E+018 | 10-03-2025 15:53 | Flipklok | 1
Mon Mar 10 15:37:57 2025 |  | 1,74162203864901E+018 | 10-03-2025 15:53 | Flipklok |  | 40
Mon Mar 10 15:37:57 2025 |  | 1,74162215834839E+018 | 10-03-2025 15:55 | Flipklok |  |  | 1
Mon Mar 10 15:37:57 2025 |  | 1,74162215839703E+018 | 10-03-2025 15:55 | Flipklok |  |  |  | 0
Mon Mar 10 15:37:57 2025 |  | 1,74162215843913E+018 | 10-03-2025 15:55 | Flipklok |  |  |  |  | 3
Mon Mar 10 15:37:57 2025 |  | 1,74162215848263E+018 | 10-03-2025 15:55 | Flipklok |  |  |  |  |  | 4
Mon Mar 10 15:37:57 2025 |  | 1,74162215852139E+018 | 10-03-2025 15:55 | Flipklok | 1
Mon Mar 10 15:37:57 2025 |  | 1,74162215858493E+018 | 10-03-2025 15:55 | Flipklok |  | 42
Mon Mar 10 15:37:57 2025 |  | 1,74162227833675E+018 | 10-03-2025 15:57 | Flipklok |  |  | 1
Mon Mar 10 15:37:57 2025 |  | 1,74162227838444E+018 | 10-03-2025 15:57 | Flipklok |  |  |  | 0
Mon Mar 10 15:37:57 2025 |  | 1,74162227843852E+018 | 10-03-2025 15:57 | Flipklok |  |  |  |  | 4
Mon Mar 10 15:37:57 2025 |  | 1,74162227847518E+018 | 10-03-2025 15:57 | Flipklok |  |  |  |  |  | 5
Mon Mar 10 15:37:57 2025 |  | 1,741622278533E+018 | 10-03-2025 15:57 | Flipklok | 1
Mon Mar 10 15:37:57 2025 |  | 1,74162227860805E+018 | 10-03-2025 15:57 | Flipklok |  | 44
Mon Mar 10 15:37:57 2025 |  | 1,74162239836521E+018 | 10-03-2025 15:59 | Flipklok |  |  | 1
Mon Mar 10 15:37:57 2025 |  | 1,74162239842672E+018 | 10-03-2025 15:59 | Flipklok |  |  |  | 0
Mon Mar 10 15:37:57 2025 |  | 1,74162239849362E+018 | 10-03-2025 15:59 | Flipklok |  |  |  |  | 5
Mon Mar 10 15:37:57 2025 |  | 1,74162239854489E+018 | 10-03-2025 15:59 | Flipklok |  |  |  |  |  | 6
Mon Mar 10 15:37:57 2025 |  | 1,74162239859276E+018 | 10-03-2025 15:59 | Flipklok | 1
Mon Mar 10 15:37:57 2025 |  | 1,7416223986525E+018 | 10-03-2025 15:59 | Flipklok |  | 45
Mon Mar 10 15:37:57 2025 |  | 1,74162248629313E+018 | 10-03-2025 16:01 | Flipklok |  |  | 0
Mon Mar 10 15:37:57 2025 |  | 1,74162248636345E+018 | 10-03-2025 16:01 | Flipklok |  |  |  | 0
Mon Mar 10 15:37:57 2025 |  | 1,74162248641554E+018 | 10-03-2025 16:01 | Flipklok |  |  |  |  | 0
Mon Mar 10 15:37:57 2025 |  | 1,7416224864898E+018 | 10-03-2025 16:01 | Flipklok |  |  |  |  |  | 0
Mon Mar 10 15:37:57 2025 |  | 1,74162248656581E+018 | 10-03-2025 16:01 | Flipklok | 0
Mon Mar 10 15:37:57 2025 |  | 1,74162248663886E+018 | 10-03-2025 16:01 | Flipklok |  | 0
Mon Mar 10 15:37:57 2025 |  | 1,74162257533921E+018 | 10-03-2025 16:02 | Flipklok |  |  | 1
Mon Mar 10 15:37:57 2025 |  | 1,74162257538171E+018 | 10-03-2025 16:02 | Flipklok |  |  |  | 0
Mon Mar 10 15:37:57 2025 |  | 1,74162257543909E+018 | 10-03-2025 16:02 | Flipklok |  |  |  |  | 0
Mon Mar 10 15:37:57 2025 |  | 1,74162257548638E+018 | 10-03-2025 16:02 | Flipklok |  |  |  |  |  | 1
Mon Mar 10 15:37:57 2025 |  | 1,7416225755331E+018 | 10-03-2025 16:02 | Flipklok | 0
Mon Mar 10 15:37:57 2025 |  | 1,74162257558424E+018 | 10-03-2025 16:02 | Flipklok |  | 0
Mon Mar 10 15:37:57 2025 |  | 1,74162263621826E+018 | 10-03-2025 16:03 | Flipklok |  |  | 2
Mon Mar 10 15:37:57 2025 |  | 1,74162263628616E+018 | 10-03-2025 16:03 | Flipklok |  |  |  | 0
Mon Mar 10 15:37:57 2025 |  | 1,74162263632475E+018 | 10-03-2025 16:03 | Flipklok |  |  |  |  | 0
Mon Mar 10 15:37:57 2025 |  | 1,74162263638805E+018 | 10-03-2025 16:03 | Flipklok |  |  |  |  |  | 2
Mon Mar 10 15:37:57 2025 |  | 1,74162263645202E+018 | 10-03-2025 16:03 | Flipklok | 0
Mon Mar 10 15:37:57 2025 |  | 1,74162263651123E+018 | 10-03-2025 16:03 | Flipklok |  | 0
Mon Mar 10 15:37:57 2025 |  | 1,74162275431894E+018 | 10-03-2025 16:05 | Flipklok |  |  | 2
Mon Mar 10 15:37:57 2025 |  | 1,74162275438812E+018 | 10-03-2025 16:05 | Flipklok |  |  |  | 1
Mon Mar 10 15:37:57 2025 |  | 1,7416227544459E+018 | 10-03-2025 16:05 | Flipklok |  |  |  |  | 0
Mon Mar 10 15:37:57 2025 |  | 1,74162275449954E+018 | 10-03-2025 16:05 | Flipklok |  |  |  |  |  | 3
Mon Mar 10 15:37:57 2025 |  | 1,74162275455941E+018 | 10-03-2025 16:05 | Flipklok | 1280
Mon Mar 10 15:37:57 2025 |  | 1,74162275460831E+018 | 10-03-2025 16:05 | Flipklok |  | 0
Mon Mar 10 15:37:57 2025 |  | 1,74162281725552E+018 | 10-03-2025 16:06 | Flipklok |  |  | 2
Mon Mar 10 15:37:57 2025 |  | 1,74162281730377E+018 | 10-03-2025 16:06 | Flipklok |  |  |  | 1
Mon Mar 10 15:37:57 2025 |  | 1,74162281734927E+018 | 10-03-2025 16:06 | Flipklok |  |  |  |  | 1
Mon Mar 10 15:37:57 2025 |  | 1,74162281739417E+018 | 10-03-2025 16:06 | Flipklok |  |  |  |  |  | 4
Mon Mar 10 15:37:57 2025 |  | 1,74162281744222E+018 | 10-03-2025 16:06 | Flipklok | 1
Mon Mar 10 15:37:57 2025 |  | 1,74162281748192E+018 | 10-03-2025 16:06 | Flipklok |  | 20
Mon Mar 10 15:37:57 2025 |  | 1,74162287533215E+018 | 10-03-2025 16:07 | Flipklok |  |  | 3
Mon Mar 10 15:37:57 2025 |  | 1,74162287539213E+018 | 10-03-2025 16:07 | Flipklok |  |  |  | 1
Mon Mar 10 15:37:57 2025 |  | 1,74162287545108E+018 | 10-03-2025 16:07 | Flipklok |  |  |  |  | 1
Mon Mar 10 15:37:57 2025 |  | 1,74162287552018E+018 | 10-03-2025 16:07 | Flipklok |  |  |  |  |  | 5
Mon Mar 10 15:37:57 2025 |  | 1,74162287557211E+018 | 10-03-2025 16:07 | Flipklok | 1
Mon Mar 10 15:37:57 2025 |  | 1,74162287560801E+018 | 10-03-2025 16:07 | Flipklok |  | 16
Mon Mar 10 15:37:57 2025 |  | 1,74162293422722E+018 | 10-03-2025 16:08 | Flipklok |  |  | 4
Mon Mar 10 15:37:57 2025 |  | 1,74162293427911E+018 | 10-03-2025 16:08 | Flipklok |  |  |  | 1
Mon Mar 10 15:37:57 2025 |  | 1,74162293431984E+018 | 10-03-2025 16:08 | Flipklok |  |  |  |  | 1
Mon Mar 10 15:37:57 2025 |  | 1,74162293436708E+018 | 10-03-2025 16:08 | Flipklok |  |  |  |  |  | 6
Mon Mar 10 15:37:57 2025 |  | 1,7416229344181E+018 | 10-03-2025 16:08 | Flipklok | 1
Mon Mar 10 15:37:57 2025 |  | 1,74162293448391E+018 | 10-03-2025 16:08 | Flipklok |  | 14
Mon Mar 10 15:37:57 2025 |  | 1,74162298233897E+018 | 10-03-2025 16:09 | Flipklok |  |  | 5
Mon Mar 10 15:37:57 2025 |  | 1,74162298241459E+018 | 10-03-2025 16:09 | Flipklok |  |  |  | 1
Mon Mar 10 15:37:57 2025 |  | 1,74162298248114E+018 | 10-03-2025 16:09 | Flipklok |  |  |  |  | 1
Mon Mar 10 15:37:57 2025 |  | 1,74162298252709E+018 | 10-03-2025 16:09 | Flipklok |  |  |  |  |  | 7
Mon Mar 10 15:37:57 2025 |  | 1,74162298259973E+018 | 10-03-2025 16:09 | Flipklok | 1
Mon Mar 10 15:37:57 2025 |  | 1,74162298267282E+018 | 10-03-2025 16:09 | Flipklok |  | 12
Mon Mar 10 15:37:57 2025 |  | 1,7416230436211E+018 | 10-03-2025 16:10 | Flipklok |  |  | 6
Mon Mar 10 15:37:57 2025 |  | 1,7416230436741E+018 | 10-03-2025 16:10 | Flipklok |  |  |  | 1
Mon Mar 10 15:37:57 2025 |  | 1,74162304371948E+018 | 10-03-2025 16:10 | Flipklok |  |  |  |  | 1
Mon Mar 10 15:37:57 2025 |  | 1,74162304378104E+018 | 10-03-2025 16:10 | Flipklok |  |  |  |  |  | 8
Mon Mar 10 15:37:57 2025 |  | 1,74162304382795E+018 | 10-03-2025 16:10 | Flipklok | 1
Mon Mar 10 15:37:57 2025 |  | 1,74162304386917E+018 | 10-03-2025 16:10 | Flipklok |  | 11
Mon Mar 10 15:37:57 2025 |  | 1,74162310535776E+018 | 10-03-2025 16:11 | Flipklok |  |  | 7
Mon Mar 10 15:37:57 2025 |  | 1,74162310541184E+018 | 10-03-2025 16:11 | Flipklok |  |  |  | 1
Mon Mar 10 15:37:57 2025 |  | 1,74162310548097E+018 | 10-03-2025 16:11 | Flipklok |  |  |  |  | 1
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

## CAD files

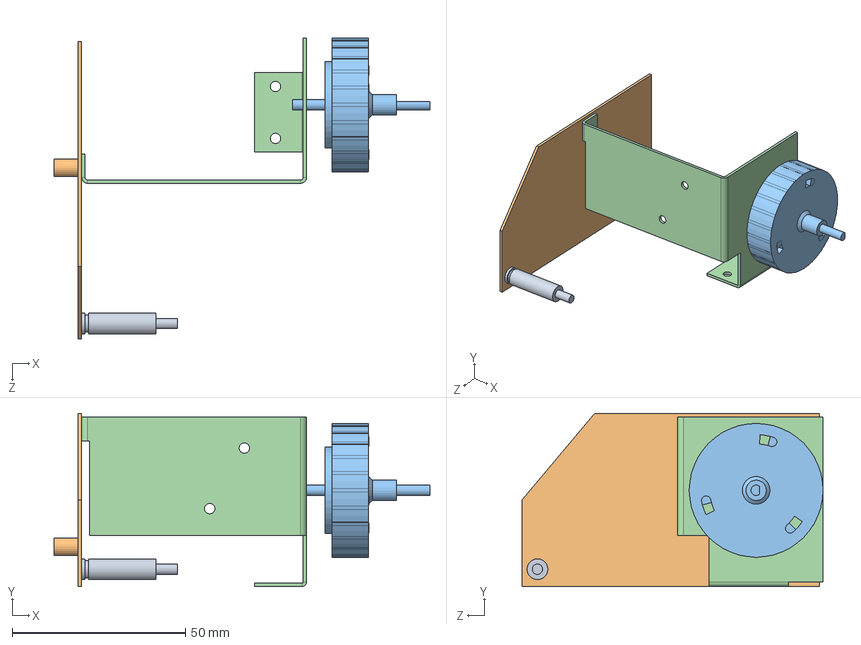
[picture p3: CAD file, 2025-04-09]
Mechanics/clock/clockAssembly.SLDASM
108.7 x 50.0 x 87.0 mm
sheetmetal-base
Alarmwheel
sheetmetal-side
post

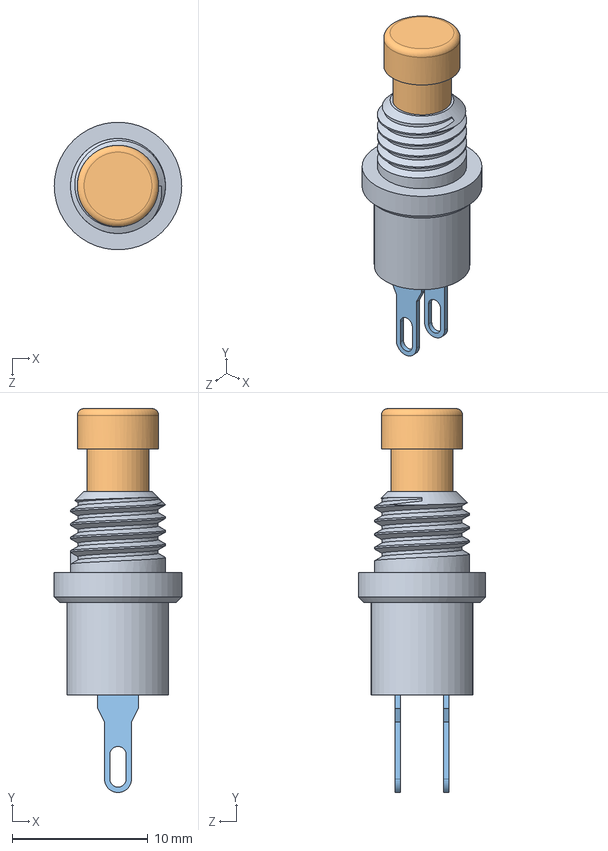
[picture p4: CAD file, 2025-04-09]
Mechanics/Pushbutton/Pushbutton.SLDASM
9.40 x 28.3 x 9.38 mm
buttoncap
pin x 2

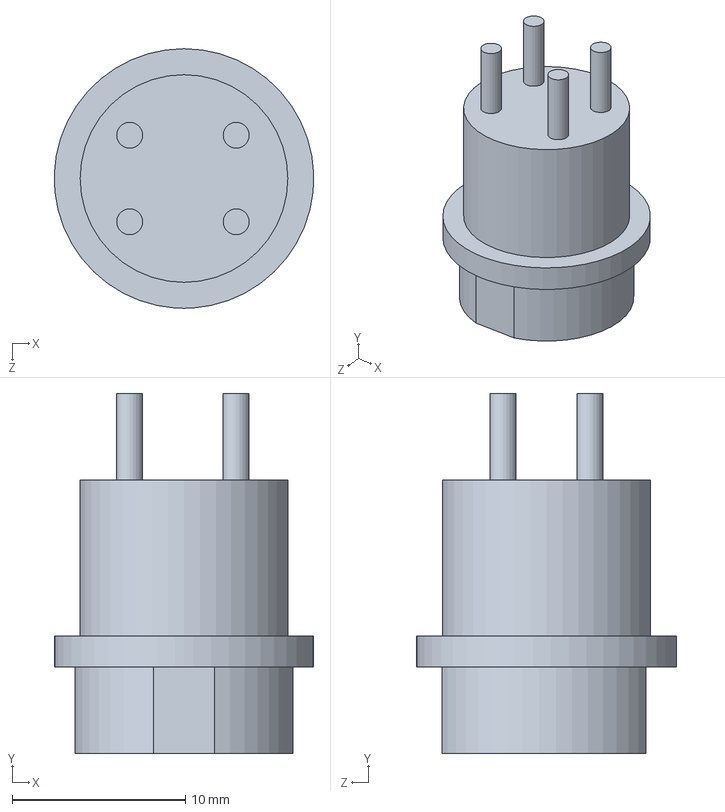
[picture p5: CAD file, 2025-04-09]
Mechanics/Connector GX16 DCF77.SLDPRT
15.0 x 20.8 x 15.0 mm

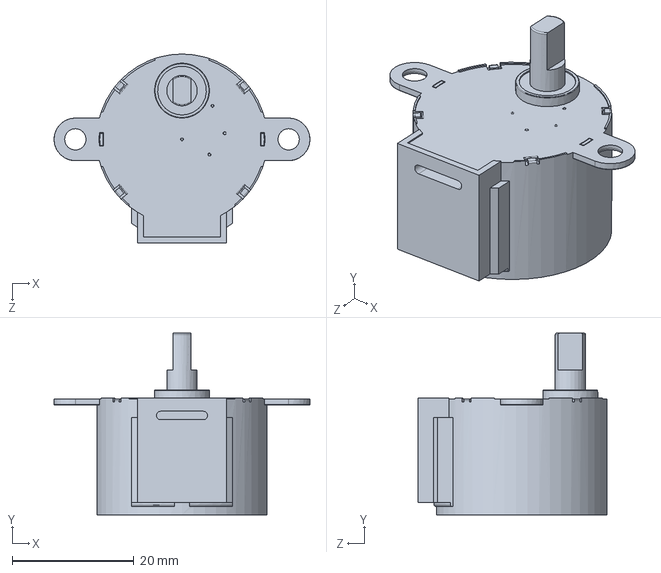
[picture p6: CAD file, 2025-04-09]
Mechanics/28byj-48 5v stepper motor.SLDPRT
42.0 x 29.8 x 31.0 mm

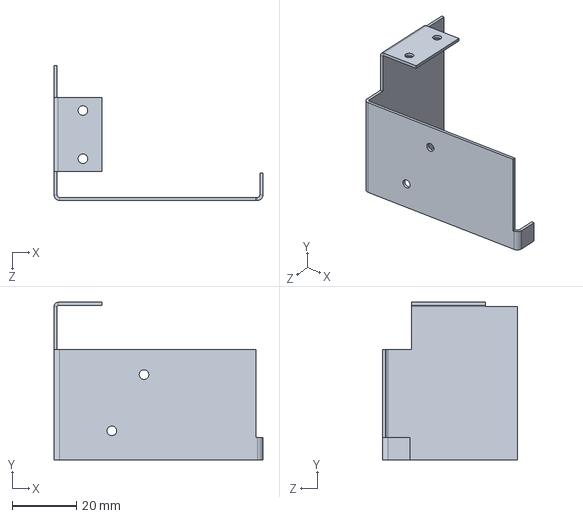
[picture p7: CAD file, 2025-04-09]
Mechanics/clock/sheetmetal-base.SLDPRT
65.0 x 49.0 x 42.0 mm

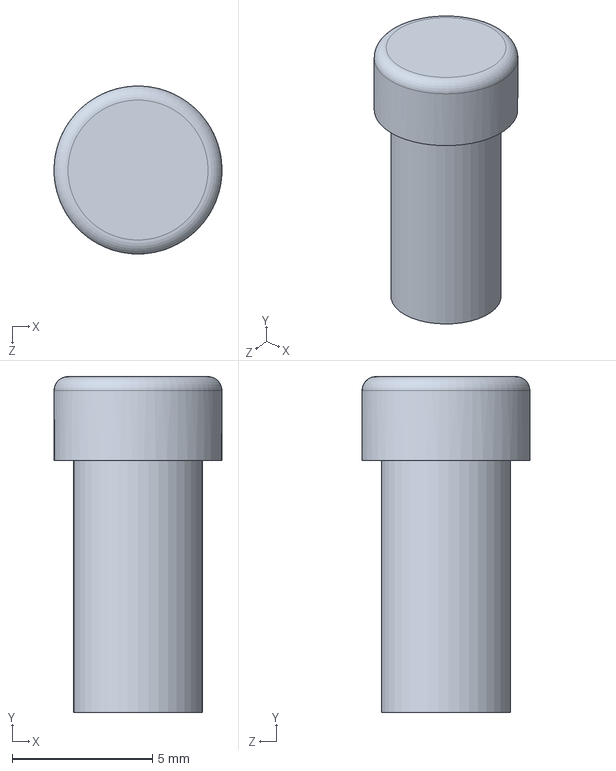
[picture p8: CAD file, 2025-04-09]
Mechanics/Pushbutton/buttoncap.SLDPRT
6.00 x 12.0 x 6.00 mm

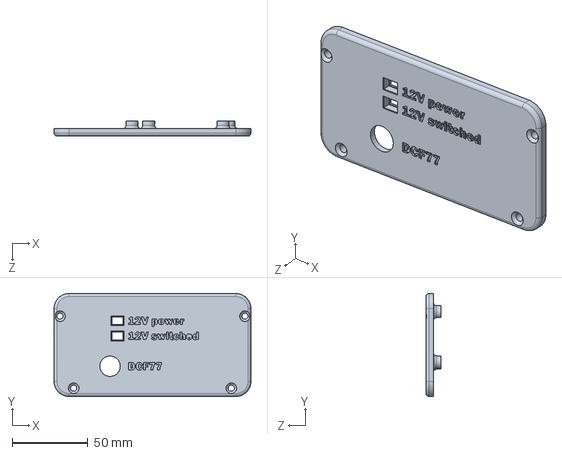
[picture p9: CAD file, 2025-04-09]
Mechanics/case-backpanel.SLDPRT
130.0 x 68.0 x 10.0 mm

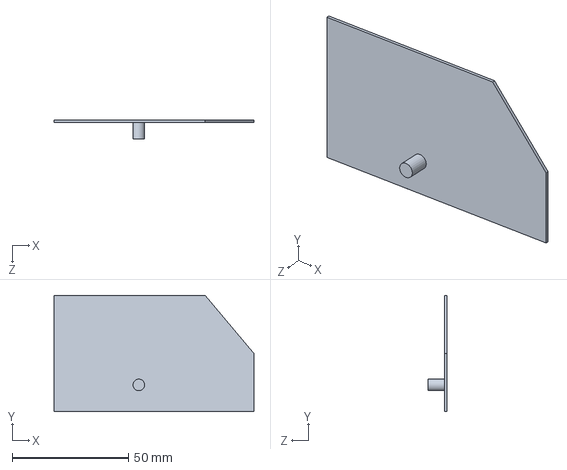
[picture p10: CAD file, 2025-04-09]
Mechanics/clock/sheetmetal-side.SLDPRT
86.0 x 50.0 x 8.00 mm

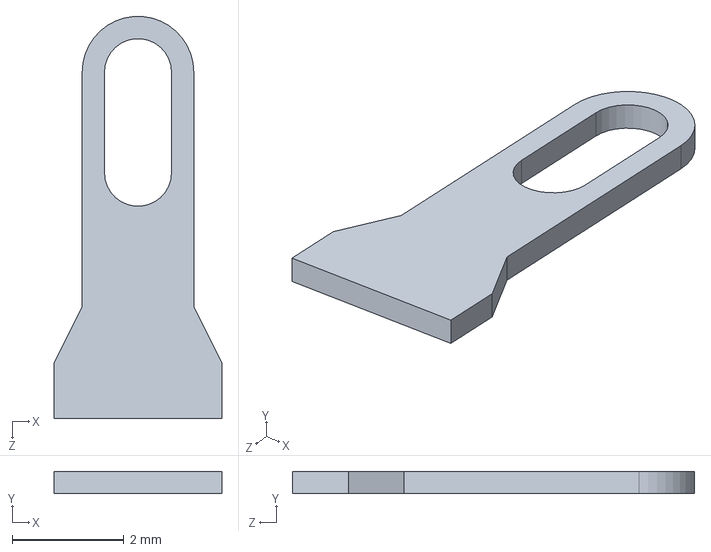
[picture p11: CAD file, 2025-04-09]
Mechanics/Pushbutton/pin.SLDPRT
3.00 x 0.4 x 7.20 mm

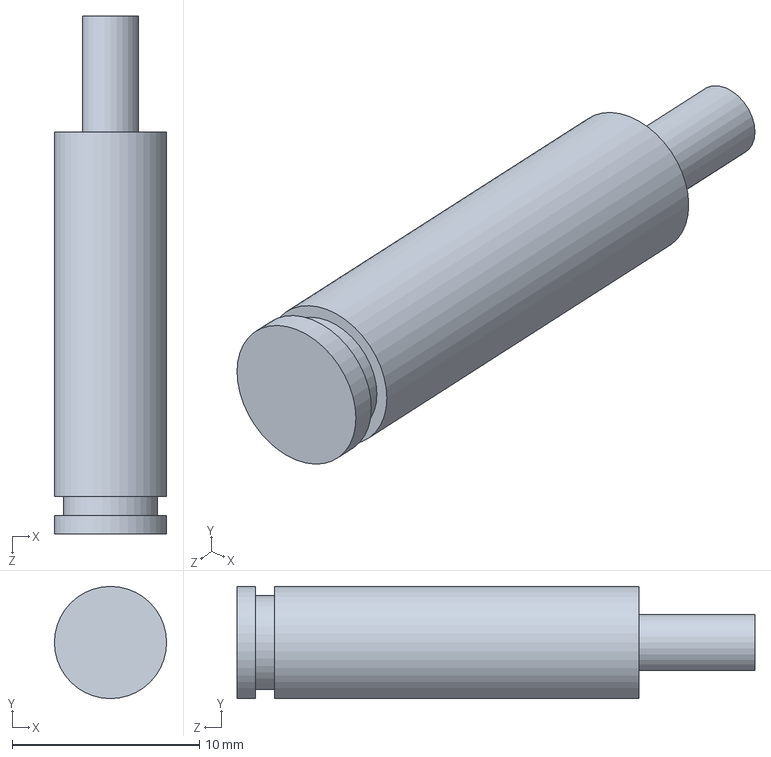
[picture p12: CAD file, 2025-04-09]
Mechanics/clock/post.SLDPRT
6.00 x 6.00 x 27.7 mm

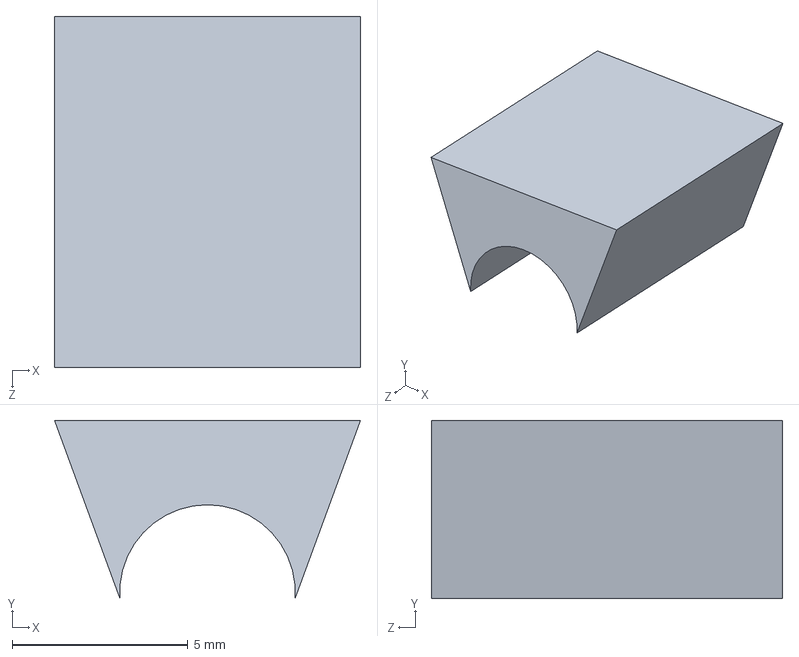
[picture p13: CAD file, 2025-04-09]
Mechanics/LED-plug.SLDPRT
8.71 x 5.07 x 10.0 mm

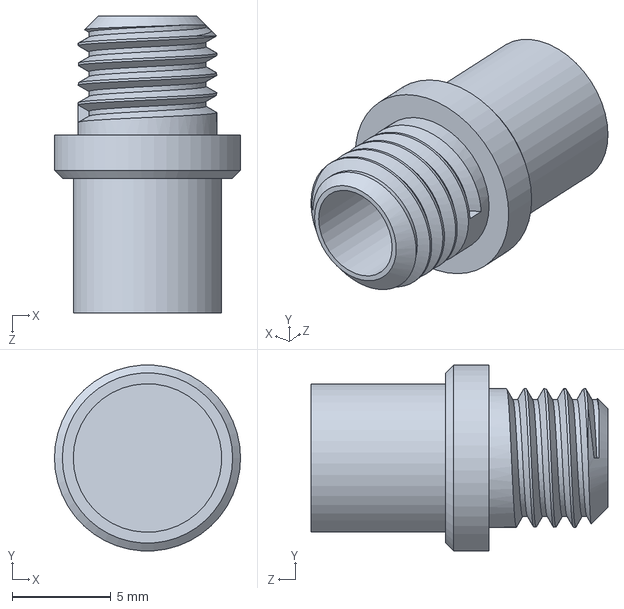
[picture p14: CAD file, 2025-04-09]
Mechanics/Pushbutton/body.SLDPRT
9.40 x 9.38 x 15.0 mm

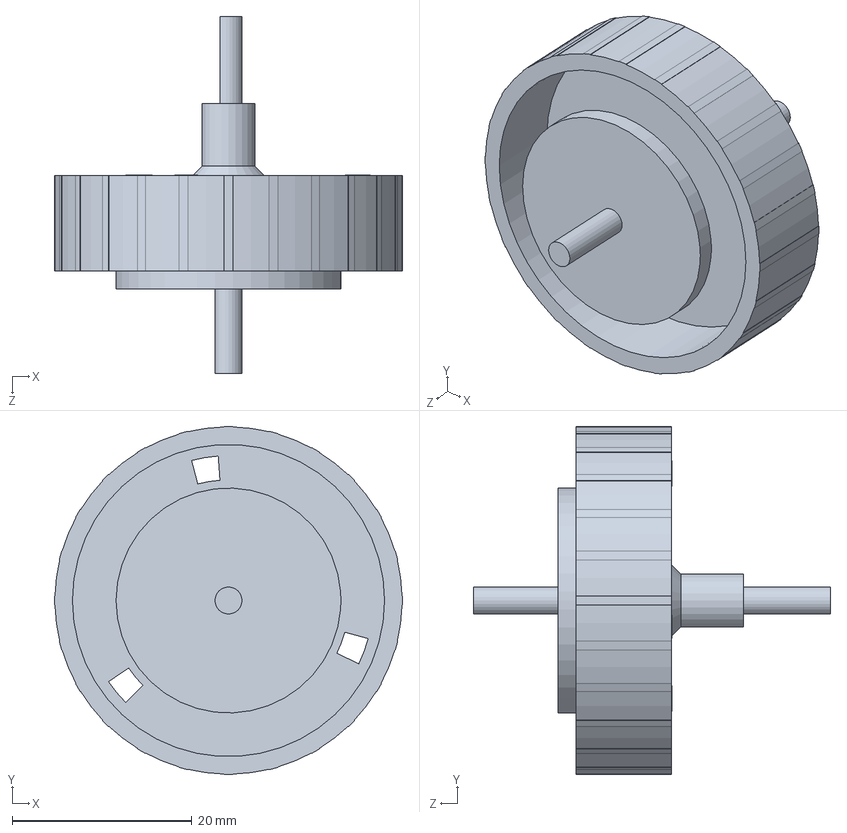
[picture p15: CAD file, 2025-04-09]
Mechanics/clock/Alarmwheel.SLDPRT
38.7 x 38.7 x 39.7 mm

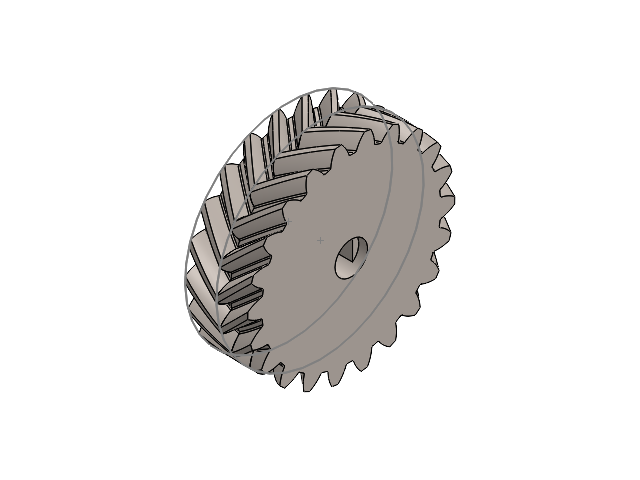
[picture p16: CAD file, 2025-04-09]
Mechanics/Gears/motorGear-1M-22T.SLDASM
helical gear_4_iso x 2

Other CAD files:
Mechanics/Gears/motorGear-1M-15T.SLDASM
Mechanics/Gears/clockGear-1M-30T.SLDASM
Mechanics/Gears/clockGear-1M-24T.SLDASM
Mechanics/Gears/clockGear-1M-35T.SLDASM
Mechanics/Flipklok-pcb.SLDASM
Mechanics/Flipklok-pcb.step
Mechanics/case.SLDPRT
Mechanics/motorHolder-v2.SLDPRT
Mechanics/motorHolder.SLDPRT
Mechanics/protective-lens.SLDPRT

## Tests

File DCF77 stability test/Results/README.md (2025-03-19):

Error rate is the percentage off the succesfull received DCF time messages which differ less then 2 minutes from NTP compared to the total DCF messages the receiver should have received. 

Total messages is calculated based on the passed time since starting receiving times the DCF messages per minute (1 message)

Time errors are errors when the received time from DCF is more than 2 minutes different than NTP time. This is caused when the time information is mangled but the parity check was passed.

Times succesfull is when the received time is less then 2 minutes off from NTP time.





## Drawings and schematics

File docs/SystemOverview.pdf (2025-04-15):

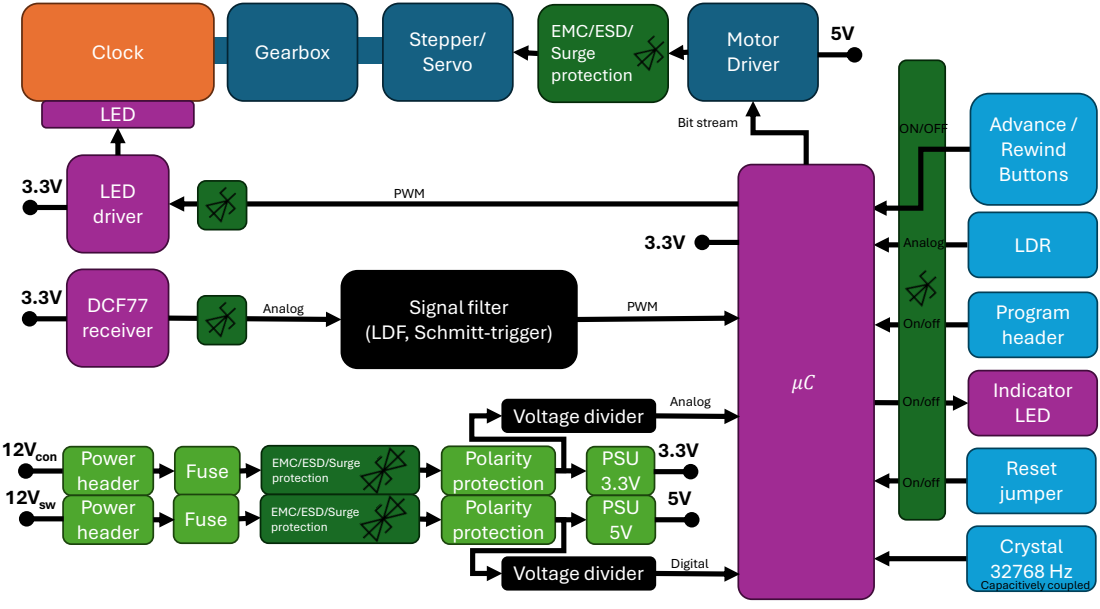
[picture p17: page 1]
Clock; Gearbox; Stepper/; Servo; Motor Driver; DCF77 receiver; LED driver; Program header; Power; header; Fuse; LED; Indicator LED; Crystal 32768 Hz; Reset jumper; PSU 3.3V; On/off; Capacitively coupled; PWM; Analog; Bit stream; Advance / Rewind Buttons; ON/OFF; PSU 5V; 12Vcon; 12Vsw; LDR; EMC/ESD/; Surge protection

Signal filter
(LDF, Schmitt-trigger)

Voltage divider
Polarity
protection
Voltage divider Digital

EMC/ESD/Surge

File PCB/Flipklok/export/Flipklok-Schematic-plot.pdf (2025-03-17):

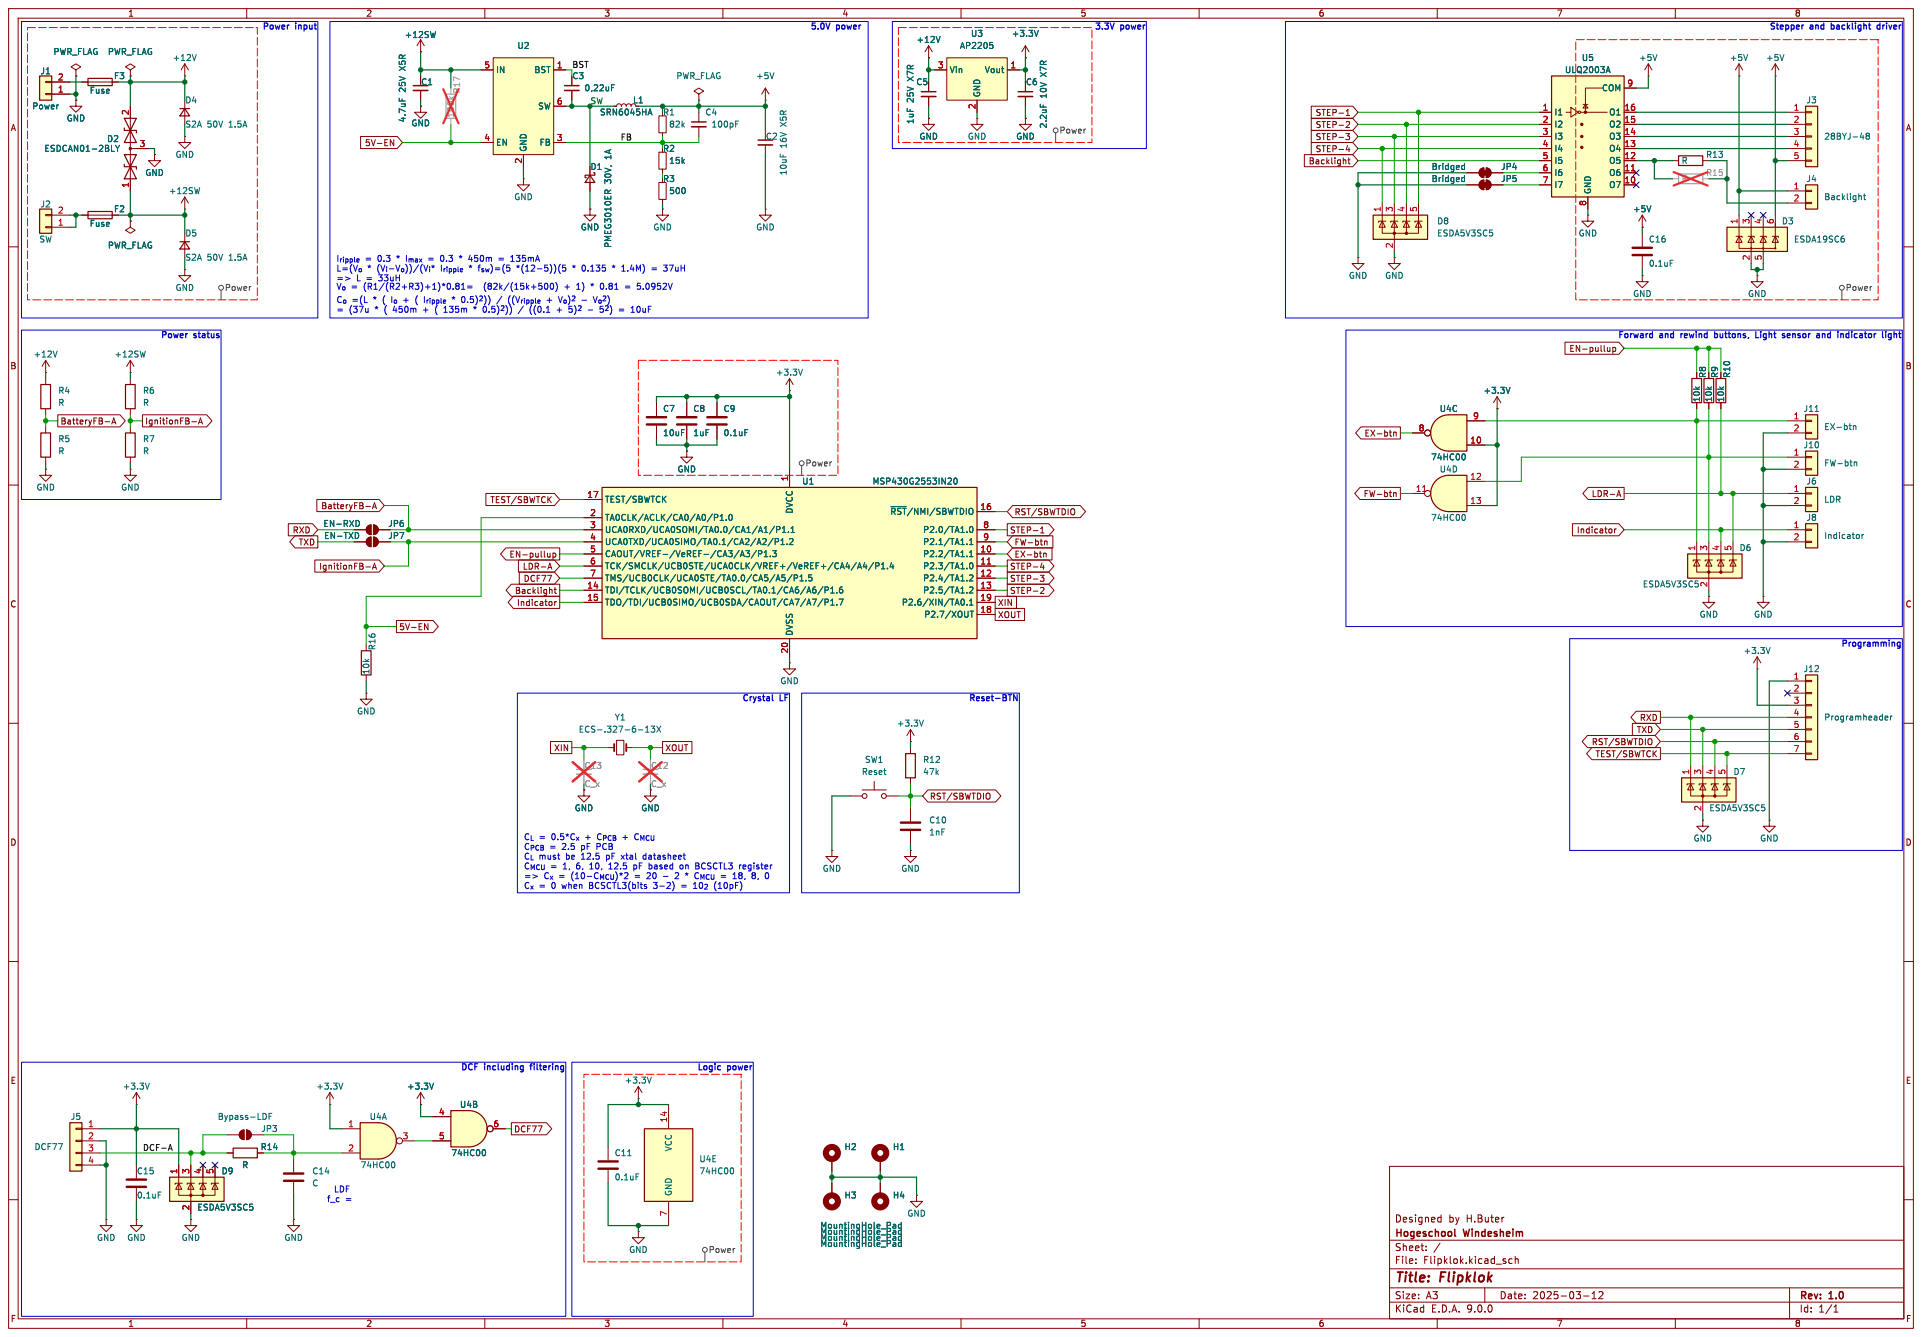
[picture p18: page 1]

2 BST 1 SW 6 FB 3 U2 GND R16 10k GND

2 BST 1 SW 6 FB 3 GND

STEP-2 STEP-1 STEP-3 STEP-4

Forward and rewind buttons, Light sensor and indicator light Reset-BTN

1 DVSS 20 TEST/SBWTCK 17 TA0CLK/ACLK/CA0/A0/P1.0 2 UCA0RXD/UCA0SOMI/TA0.0/CA1/A1/P1.1 3 UCA0TXD/UCA0SIMO/TA0.1/CA2/A2/P1.2 4 CAOUT/VREF-/VeREF-/CA3/A3/P1.3 5 TCK/SMCLK/UCB0STE/UCA0CLK/VREF+/VeREF+/CA4/A4/P1.4 6 TMS/UCB0CLK/UCA0STE/TA0.0/CA5/A5/P1.5 7 TDI/TCLK/UCB0SOMI/UCB0SCL/TA0.1/CA6/A6/P1.6 14 TDO/TDI/UCB0SIMO/UCB0SDA/CAOUT/CA7/A7/P1.7 15 U1 MSP430G2553IN20 +12SW

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

XOUTSTEP-4 STEP-3 RST/SBWTDIO
STEP-1 EX-btn FW-btn

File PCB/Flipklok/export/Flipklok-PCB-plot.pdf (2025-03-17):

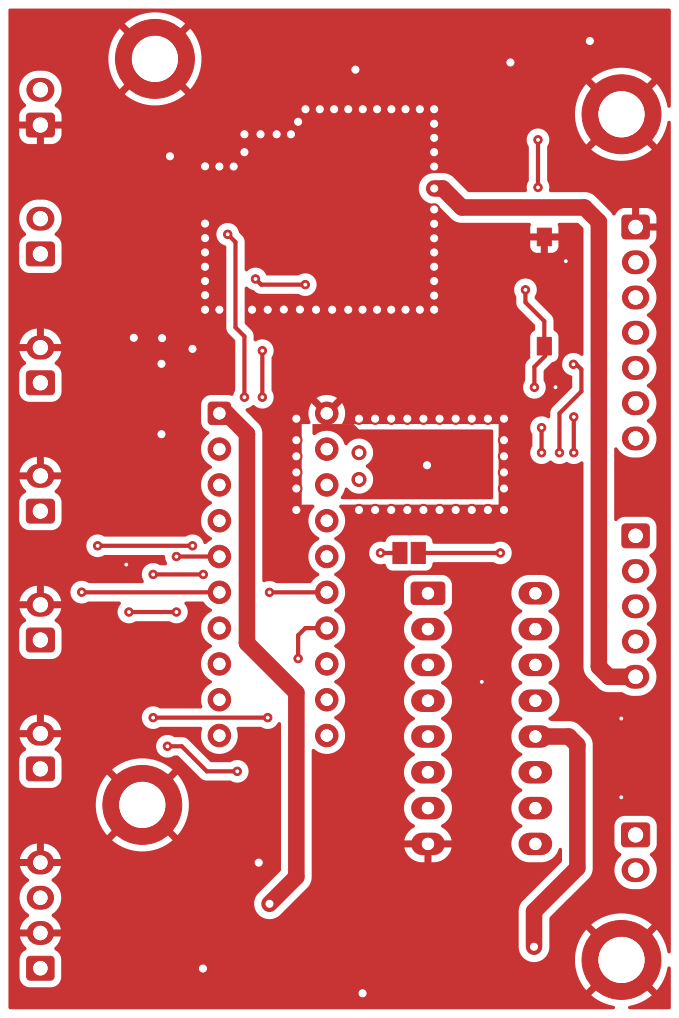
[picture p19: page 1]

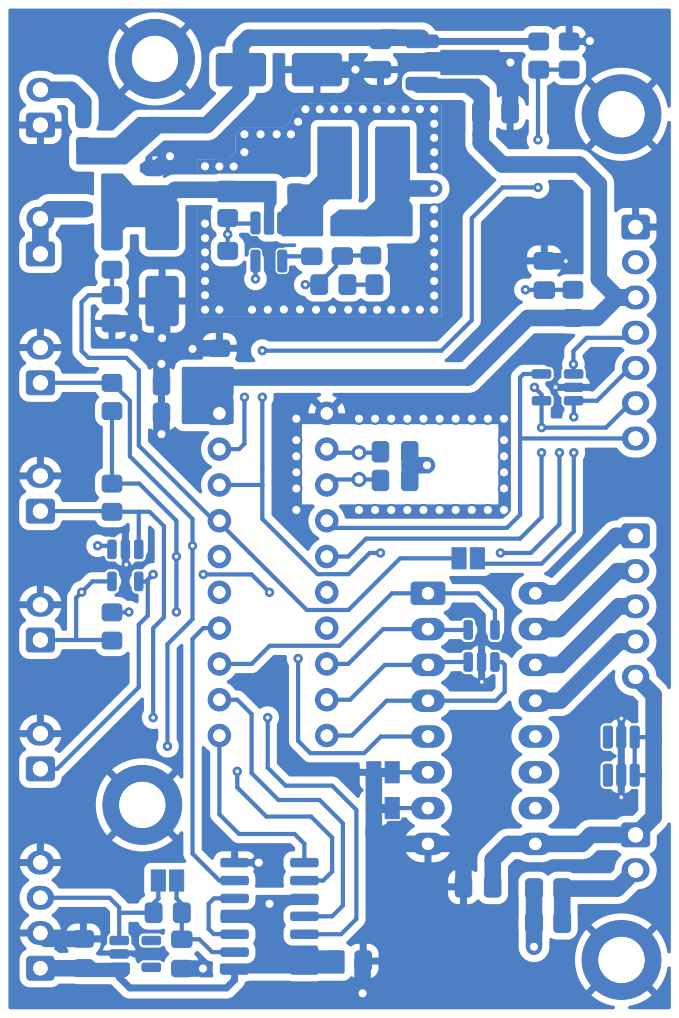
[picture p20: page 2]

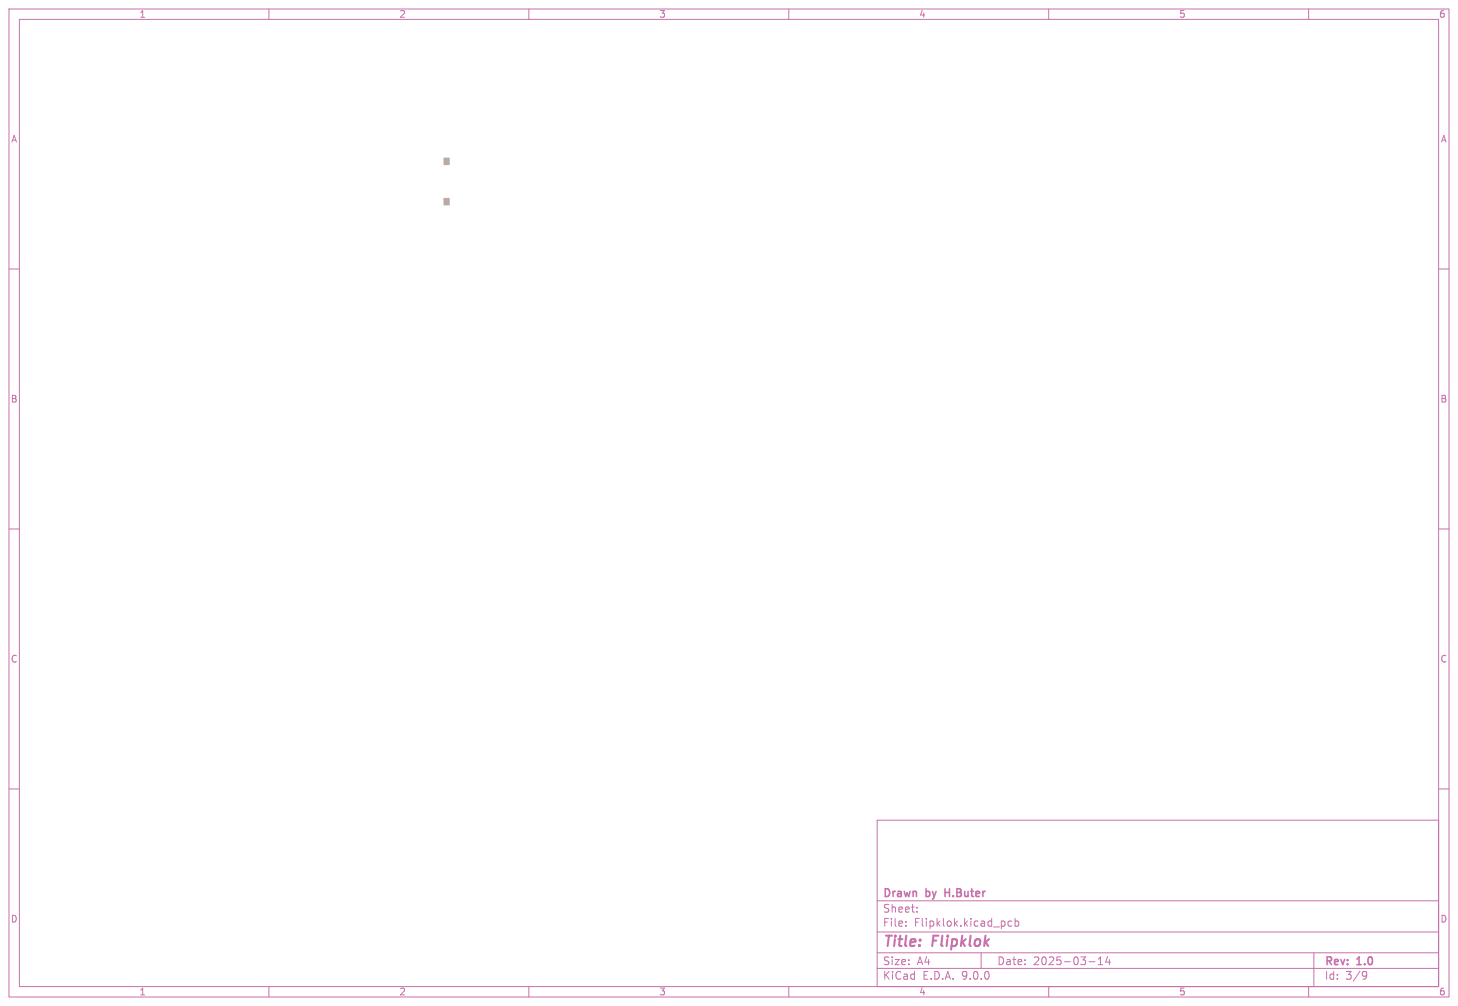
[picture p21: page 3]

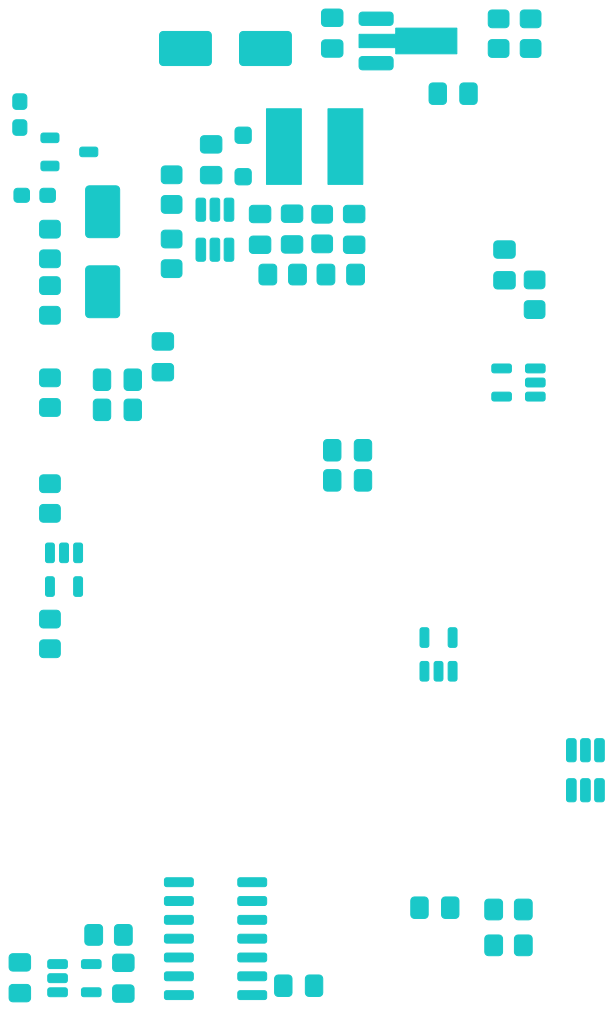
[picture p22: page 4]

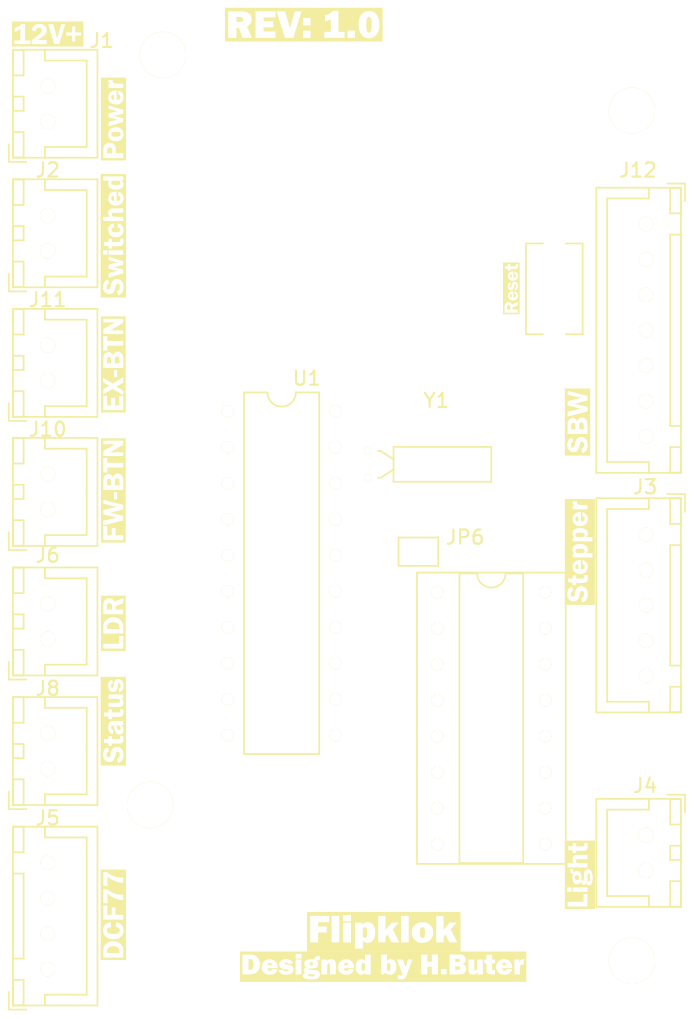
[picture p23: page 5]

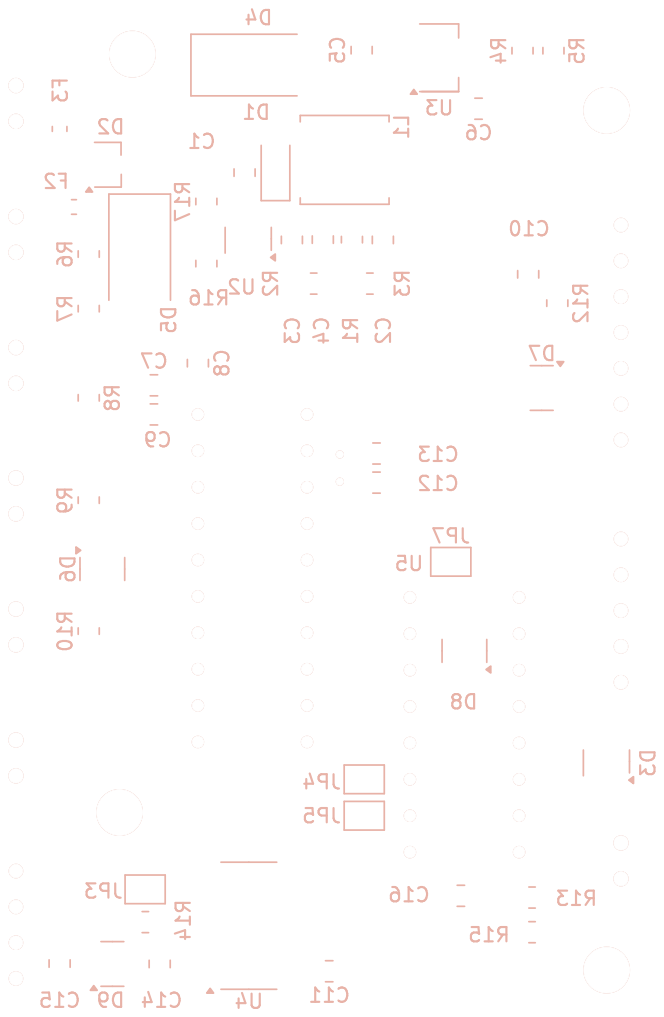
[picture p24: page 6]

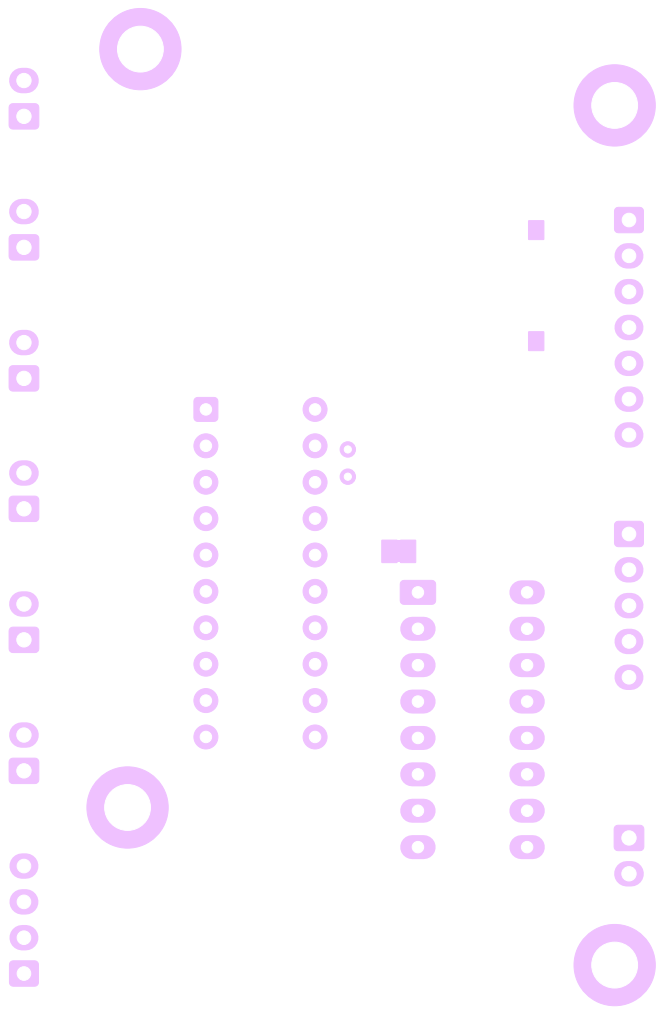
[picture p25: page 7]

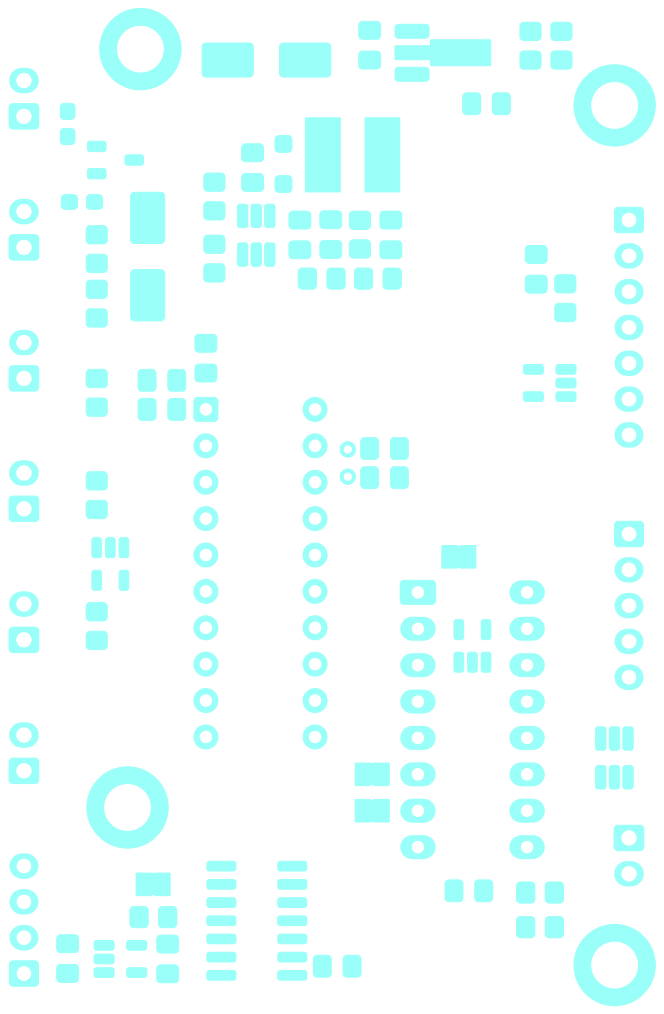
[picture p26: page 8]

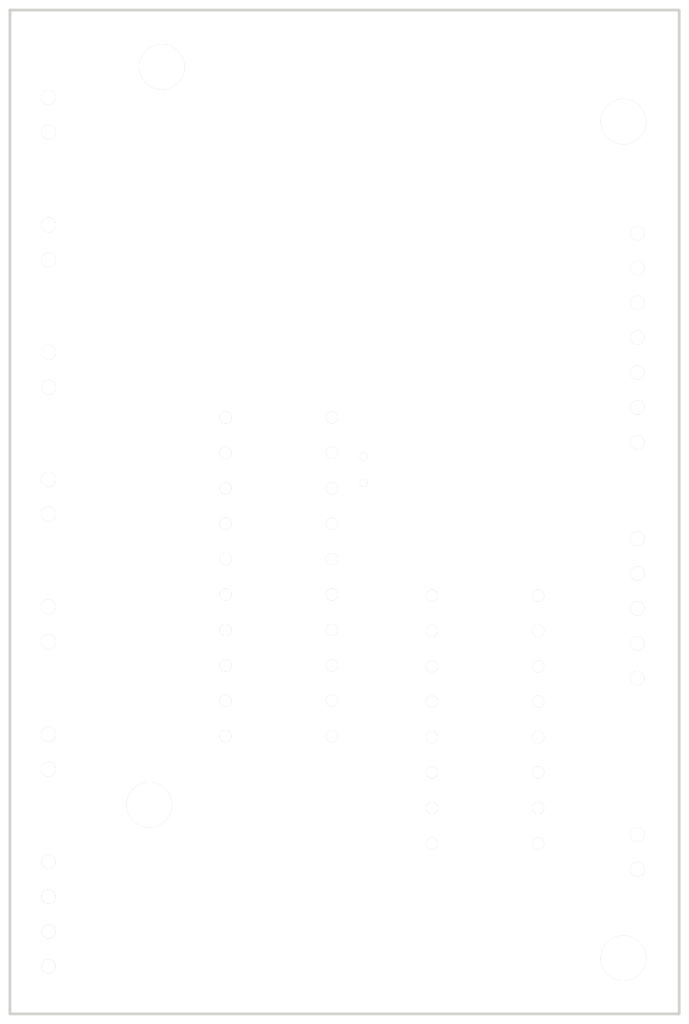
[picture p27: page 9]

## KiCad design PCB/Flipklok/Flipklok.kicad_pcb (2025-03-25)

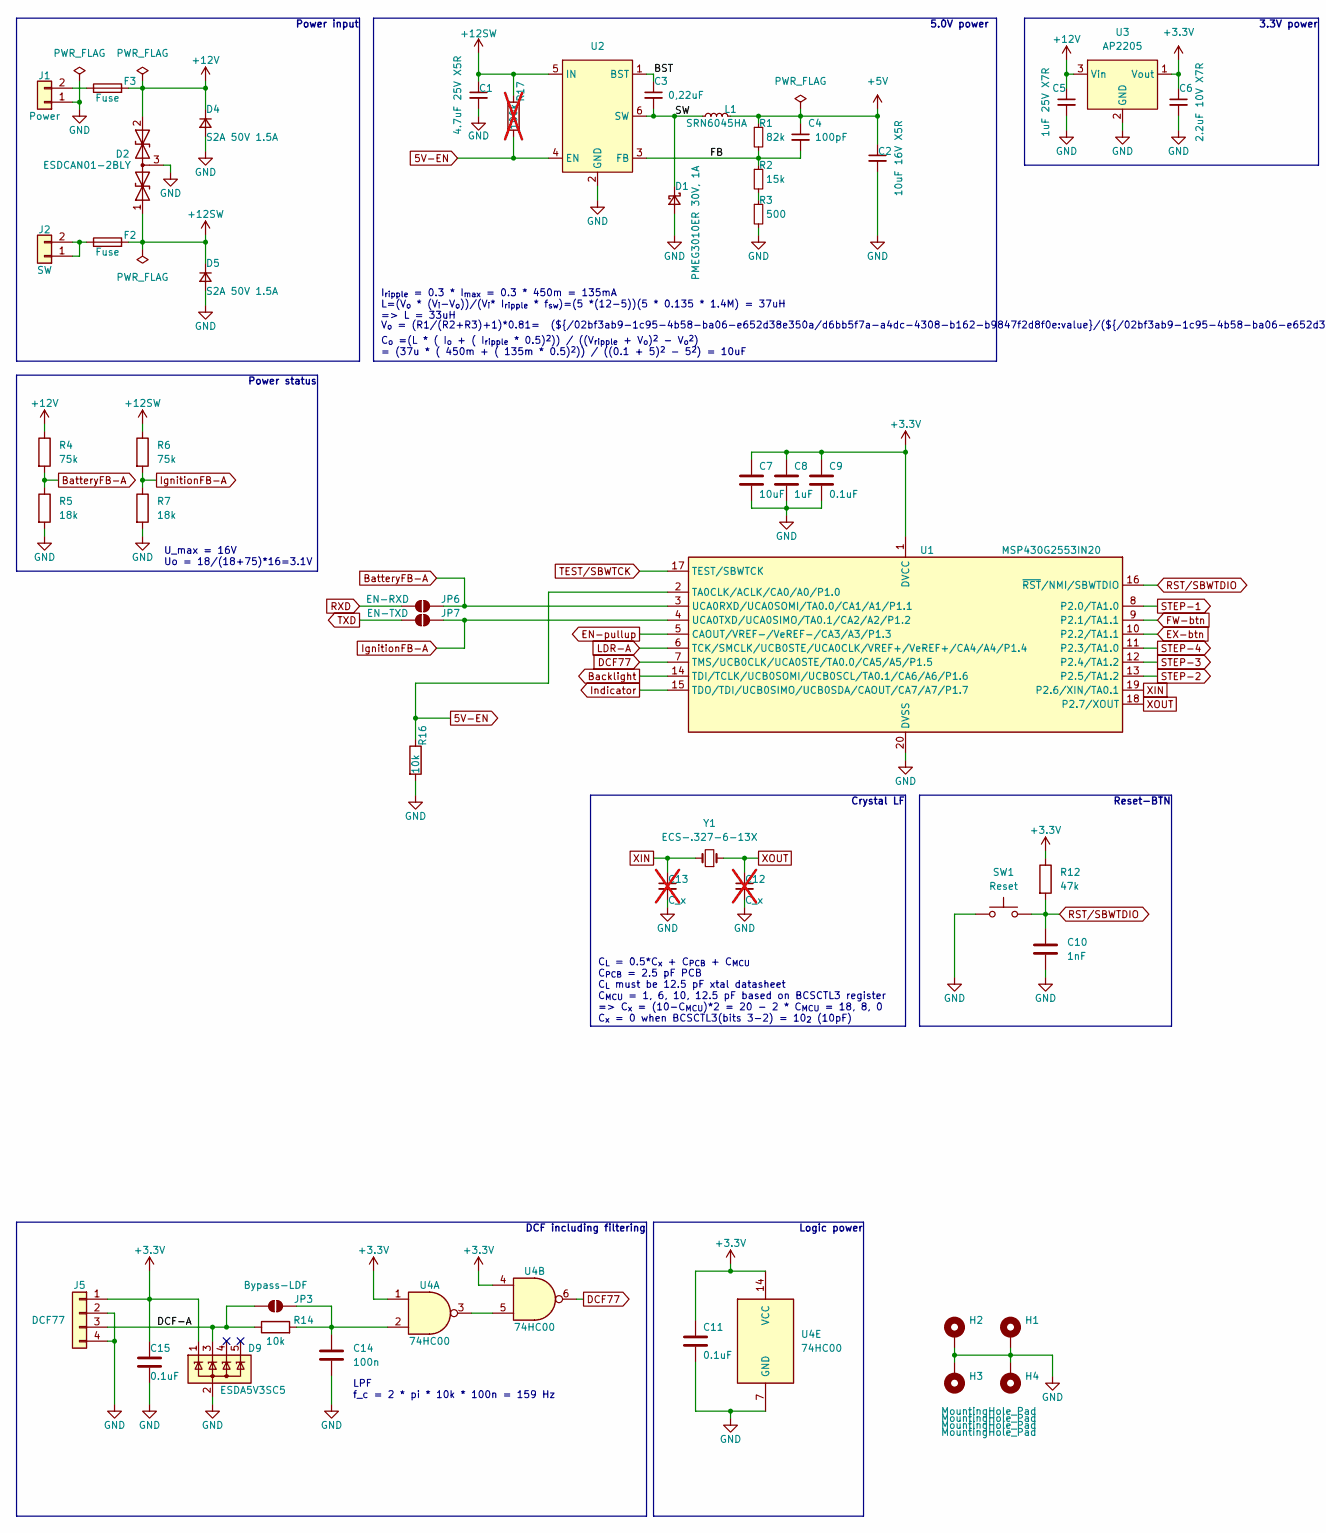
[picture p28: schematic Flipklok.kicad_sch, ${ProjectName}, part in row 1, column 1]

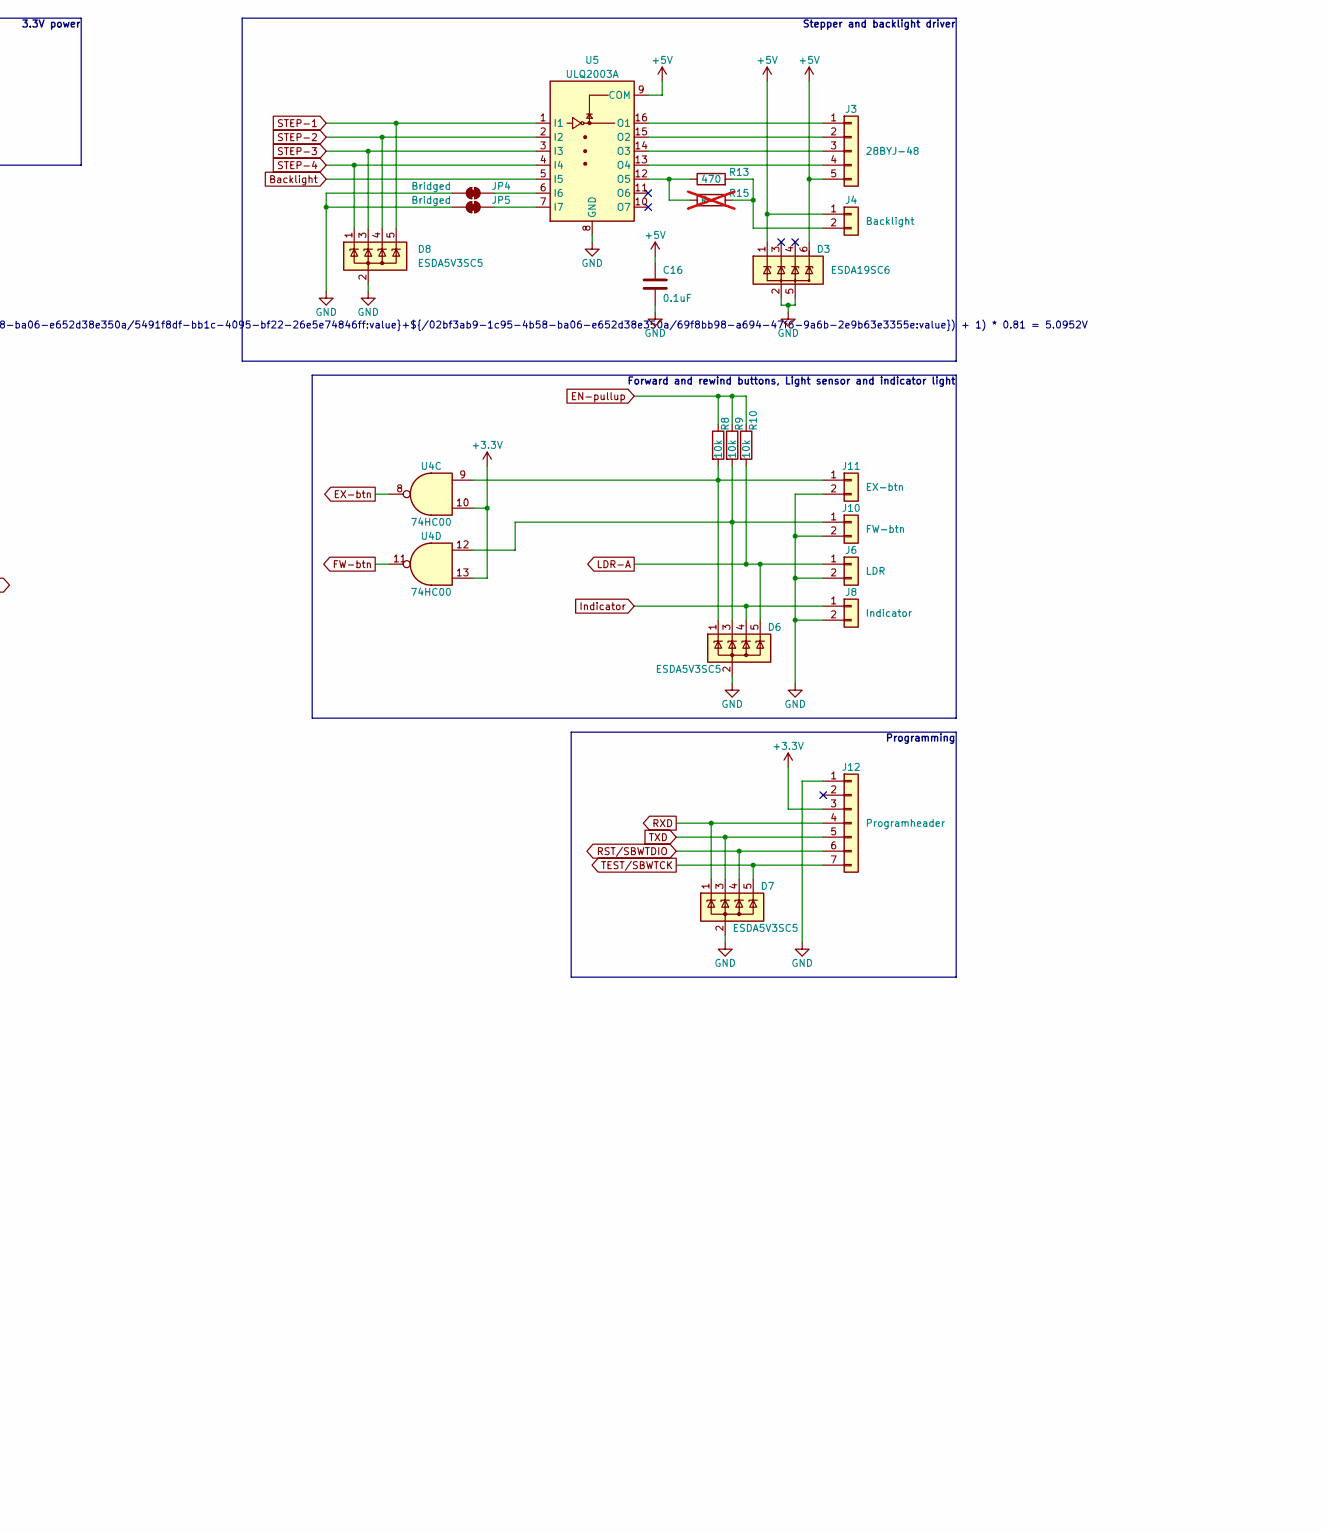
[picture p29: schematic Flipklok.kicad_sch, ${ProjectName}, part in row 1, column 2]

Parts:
C1: 4.7uF 25V X5R; C_0805_2012Metric_Pad1.18x1.45mm_HandSolder
C2: 10uF 16V X5R; C_0805_2012Metric_Pad1.18x1.45mm_HandSolder
C3: 0,22uF; C_0805_2012Metric_Pad1.18x1.45mm_HandSolder
C4: 100pF; C_0805_2012Metric_Pad1.18x1.45mm_HandSolder
C5: 1uF 25V X7R; C_0805_2012Metric_Pad1.18x1.45mm_HandSolder
C6: 2.2uF 10V X7R; C_0805_2012Metric_Pad1.18x1.45mm_HandSolder
C7: 10uF; C_0805_2012Metric_Pad1.18x1.45mm_HandSolder
C8: 1uF; C_0805_2012Metric_Pad1.18x1.45mm_HandSolder
C9, C11, C15, C16: 0.1uF; C_0805_2012Metric_Pad1.18x1.45mm_HandSolder
C10: 1nF; C_0805_2012Metric_Pad1.18x1.45mm_HandSolder
C12, C13: C_x; C_0805_2012Metric_Pad1.18x1.45mm_HandSolder; not fitted
C14: 100n; C_0805_2012Metric_Pad1.18x1.45mm_HandSolder
D1: PMEG3010ER 30V, 1A; D_SOD-123F
D2: ESDCAN01-2BLY; TSOT-23
D3: ESDA19SC6; SOT-23-6_Handsoldering
D4, D5: S2A 50V 1.5A; D_SMB_Handsoldering
D6, D7, D8, D9: ESDA5V3SC5; SOT-23-5
F2, F3: Fuse; Fuse_0603_1608Metric_Pad1.05x0.95mm_HandSolder
H1, H2, H3, H4: MountingHole_Pad; MountingHole_3.2mm_M3_DIN965_Pad_TopBottom
J1: Power; JST_XH_B2B-XH-A_1x02_P2.50mm_Vertical
J2: SW; JST_XH_B2B-XH-A_1x02_P2.50mm_Vertical
J3: 28BYJ-48; JST_XH_B5B-XH-A_1x05_P2.50mm_Vertical
J4: Backlight; JST_XH_B2B-XH-A_1x02_P2.50mm_Vertical
J5: DCF77; JST_XH_B4B-XH-A_1x04_P2.50mm_Vertical
J6: LDR; JST_XH_B2B-XH-A_1x02_P2.50mm_Vertical
J8: Indicator; JST_XH_B2B-XH-A_1x02_P2.50mm_Vertical
J10: FW-btn; JST_XH_B2B-XH-A_1x02_P2.50mm_Vertical
J11: EX-btn; JST_XH_B2B-XH-A_1x02_P2.50mm_Vertical
J12: Programheader; JST_XH_B7B-XH-A_1x07_P2.50mm_Vertical
JP3: Bypass-LDF; SolderJumper-2_P1.3mm_Open_Pad1.0x1.5mm
JP4, JP5: Bridged; SolderJumper-2_P1.3mm_Bridged_Pad1.0x1.5mm
JP6: EN-RXD; SolderJumper-2_P1.3mm_Open_Pad1.0x1.5mm
JP7: EN-TXD; SolderJumper-2_P1.3mm_Open_Pad1.0x1.5mm
L1: SRN6045HA; L_Bourns_SRN6045TA
R1: 82k; R_0805_2012Metric_Pad1.20x1.40mm_HandSolder
R2: 15k; R_0805_2012Metric_Pad1.20x1.40mm_HandSolder
R3: 500; R_0805_2012Metric_Pad1.20x1.40mm_HandSolder
R4, R6: 75k; R_0805_2012Metric_Pad1.20x1.40mm_HandSolder
R5, R7: 18k; R_0805_2012Metric_Pad1.20x1.40mm_HandSolder
R8, R9, R10, R14, R16: 10k; R_0805_2012Metric_Pad1.20x1.40mm_HandSolder
R12: 47k; R_0805_2012Metric_Pad1.20x1.40mm_HandSolder
R13: 470; R_0805_2012Metric_Pad1.20x1.40mm_HandSolder
R15: R; R_0805_2012Metric_Pad1.20x1.40mm_HandSolder; not fitted
R17: 100k; R_0805_2012Metric_Pad1.20x1.40mm_HandSolder; not fitted
SW1: Reset; SW_Tactile_SPST_NO_Straight_CK_PTS636Sx25SMTRLFS
U1: MSP430G2553IN20; DIP-20_W7.62mm
U2: SOT-23-6_Handsoldering
U3: AP2205; SOT-89-3_Handsoldering
U4: 74HC00; SOIC-14_3.9x8.7mm_P1.27mm
U5: ULQ2003A; DIP-16_W7.62mm_Socket_LongPads
Y1: ECS-.327-6-13X; Crystal_C26-LF_D2.1mm_L6.5mm_Horizontal

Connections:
5V-EN: R16.1, R17.2, U1.2 (TA0CLK/ACLK/CA0/A0/P1.0), U2.4 (EN)
+3.3V: C6.1, C7.1, C8.1, C9.1, C11.1, C15.1, D9.1 (K), J5.1, J12.3, R12.1, U1.1 (DVCC), U3.1 (Vout), U4.1, U4.4, U4.10, U4.13, U4.14 (VCC)
+5V: C2.1, C4.1, C16.1, D3.1 (IO1), D3.6 (IO5), J3.5, J4.1, L1.2, R1.1, U5.9 (COM)
+12SW: C1.1, D2.1 (A1), D5.1 (K), F2.2, R6.1, R17.1, U2.5 (IN)
+12V: C5.1, D2.2 (A2), D4.1 (K), F3.2, R4.1, U3.3 (Vin)
/BST: C3.1, U2.1 (BST)
/DCF-A: D9.3 (K), J5.3, JP3.1 (A), R14.1
/FB: C4.2, R1.2, R2.1, U2.3 (FB)
/SW: C3.2, D1.1 (K), L1.1, U2.6 (SW)
Backlight: U1.14 (TDI/TCLK/UCB0SOMI/UCB0SCL/TA0.1/CA6/A6/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), U5.5 (I5)
BatteryFB-A: JP6.2 (B), R4.2, R5.1, U1.3 (UCA0RXD/UCA0SOMI/TA0.0/CA1/A1/P1.1)
DCF77: U1.7 (TMS/UCB0CLK/UCA0STE/TA0.0/CA5/A5/P1.5), U4.6
EN-pullup: R8.1, R9.1, R10.1, U1.5 (CAOUT/VREF-/VeREF-/CA3/A3/P1.3)
EX-btn: U1.10 (P2.2/TA1.1), U4.8
FW-btn: U1.9 (P2.1/TA1.1), U4.11
GND: C1.2, C2.2, C5.2, C6.2, C7.2, C8.2, C9.2, C10.2, C11.2, C12.2, C13.2, C14.2, C15.2, C16.2, D1.2 (A), D2.3 (common), D3.2 (GND), D3.5 (IO4), D4.2 (A), D5.2 (A), D6.2 (A), D7.2 (A), D8.2 (A), D9.2 (A), H1.1, H2.1, H3.1, H4.1, J1.1, J5.2, J5.4, J6.2, J8.2, J10.2, J11.2, J12.1, JP4.1 (A), JP5.1 (A), R3.2, R5.2, R7.2, R16.2, SW1.1, U1.20 (DVSS), U2.2 (GND), U3.2 (GND), U4.7 (GND), U5.8 (GND)
IgnitionFB-A: JP7.2 (B), R6.2, R7.1, U1.4 (UCA0TXD/UCA0SIMO/TA0.1/CA2/A2/P1.2)
Indicator: D6.4 (K), J8.1, U1.15 (TDO/TDI/UCB0SIMO/UCB0SDA/CAOUT/CA7/A7/P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)
LDR-A: D6.5 (K), J6.1, R10.2, U1.6 (TCK/SMCLK/UCB0STE/UCA0CLK/VREF+/VeREF+/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)
unnamed: F3.1, J1.2
unnamed: F2.1, J2.1, J2.2
unnamed: J3.1, U5.16 (O1)
unnamed: J3.2, U5.15 (O2)
unnamed: J3.3, U5.14 (O3)
unnamed: J3.4, U5.13 (O4)
unnamed: J4.2, R13.2, R15.2
unnamed: D6.3 (K), J10.1, R9.2, U4.12
unnamed: D6.1 (K), J11.1, R8.2, U4.9
unnamed: C14.1, JP3.2 (B), R14.2, U4.2
unnamed: JP4.2 (B), U5.6 (I6)
unnamed: JP5.2 (B), U5.7 (I7)
unnamed: R2.2, R3.1
unnamed: U4.3, U4.5
unnamed: R13.1, R15.1, U5.12 (O5)
RST/SBWTDIO: C10.1, D7.4 (K), J12.6, R12.2, SW1.2, U1.16 (~RST/NMI/SBWTDIO)
RXD: D7.1 (K), J12.4, JP6.1 (A)
STEP-1: D8.5 (K), U1.8 (P2.0/TA1.0), U5.1 (I1)
STEP-2: D8.4 (K), U1.13 (P2.5/TA1.2), U5.2 (I2)
STEP-3: D8.3 (K), U1.12 (P2.4/TA1.2), U5.3 (I3)
STEP-4: D8.1 (K), U1.11 (P2.3/TA1.0), U5.4 (I4)
TEST/SBWTCK: D7.5 (K), J12.7, U1.17 (TEST/SBWTCK)
TXD: D7.3 (K), J12.5, JP7.1 (A)
XIN: C13.1, U1.19 (P2.6/XIN/TA0.1), Y1.2
XOUT: C12.1, U1.18 (P2.7/XOUT), Y1.1

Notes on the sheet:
Power status
I_{ripple} = 0.3 * I_{max} = 0.3 * 450m = 135mA L=(V_{o} * (V_{i}-V_{o}))/(V_{i}* I_{ripple} * f_{sw})=(5 *(12-5))(5 * 0.135 * 1.4M) = 37uH => L = 33uH
LPF f_c = 2 * pi * 10k * 100n = 159 Hz
Power input
Reset-BTN
C_{o} =(L * ( I_{o} + ( I_{ripple} * 0.5)^{2})) / ((V_{ripple} + V_{o})^{2} - V_{o}^{2}) = (37u * ( 450m + ( 135m * 0.5)^{2})) / ((0.1 + 5)^{2} - 5^{2}) = 10uF
5.0V power
Crystal LF
C_{L} = 0.5*C_{x} + C_{PCB} + C_{MCU} C_{PCB} = 2.5 pF PCB C_{L} must be 12.5 pF xtal datasheet C_{MCU} = 1, 6, 10, 12.5 pF based on BCSCTL3 register => C_{x} = (10-C_{MCU})*2 = 20 - 2 * C_{MCU} = 18, 8, 0 C_{x} = 0 when BCSCTL3(bits 3-2) = 10_{2} (10pF)
3.3V power
U_max = 16V Uo = 18/(18+75)*16=3.1V
V_{o} = (R1/(R2+R3)+1)*0.81= (${/02bf3ab9-1c95-4b58-ba06-e652d38e350a/d6bb5f7a-a4dc-4308-b162-b9847f2d8f0e:value}/(${/02bf3ab9-1c95-4b58-ba06-e652d38e350a/5491f8df-bb1c-4095-bf22-26e5e74846ff:value}+${/02bf3ab9-1c95-4b58-ba06-e652d38e350a/69f8bb98-a694-47f6-9a6b-2e9b63e3355e:value}) + 1) * 0.81 = 5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
Forward and rewind buttons, Light sensor and indicator light
DCF including filtering
Programming
Stepper and backlight driver
Logic power

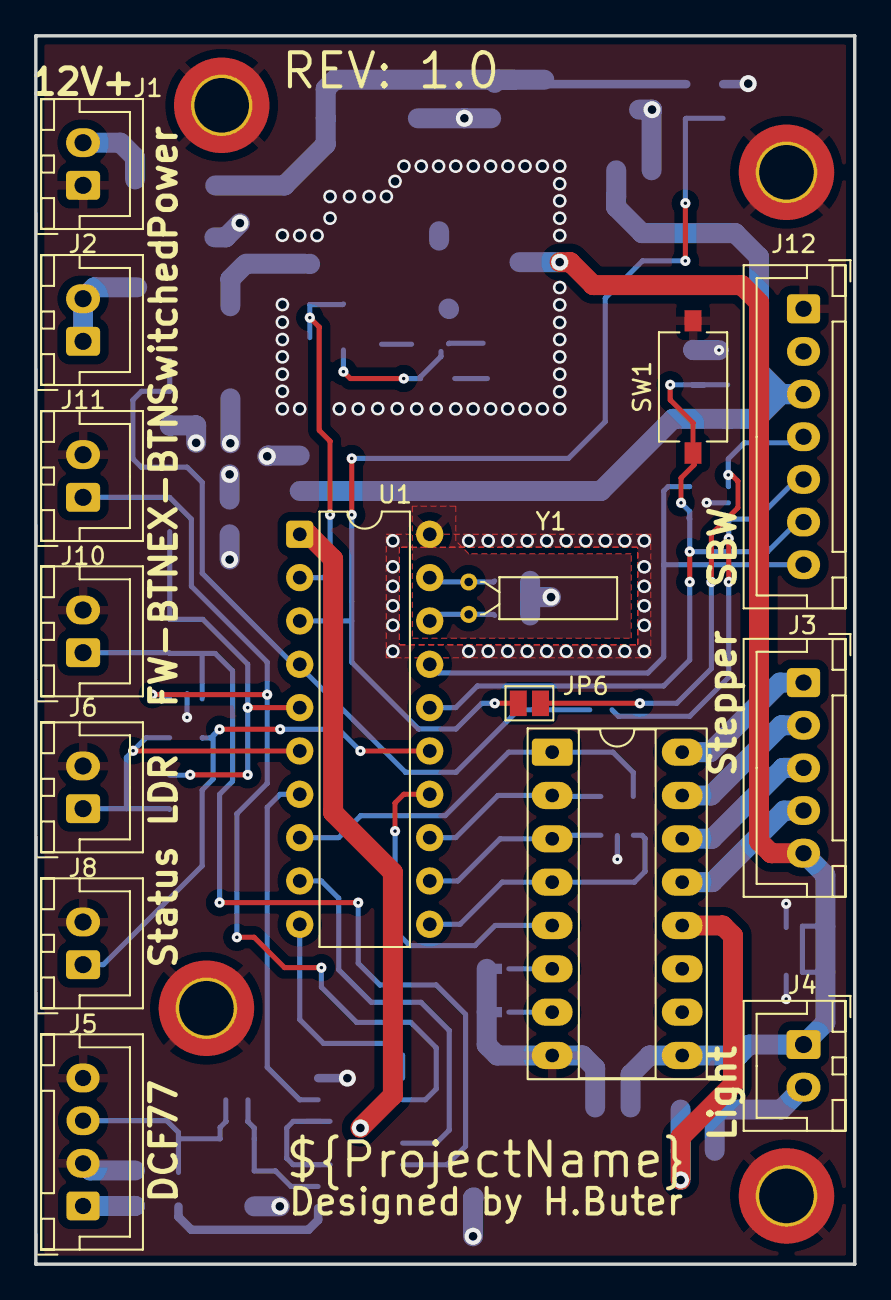
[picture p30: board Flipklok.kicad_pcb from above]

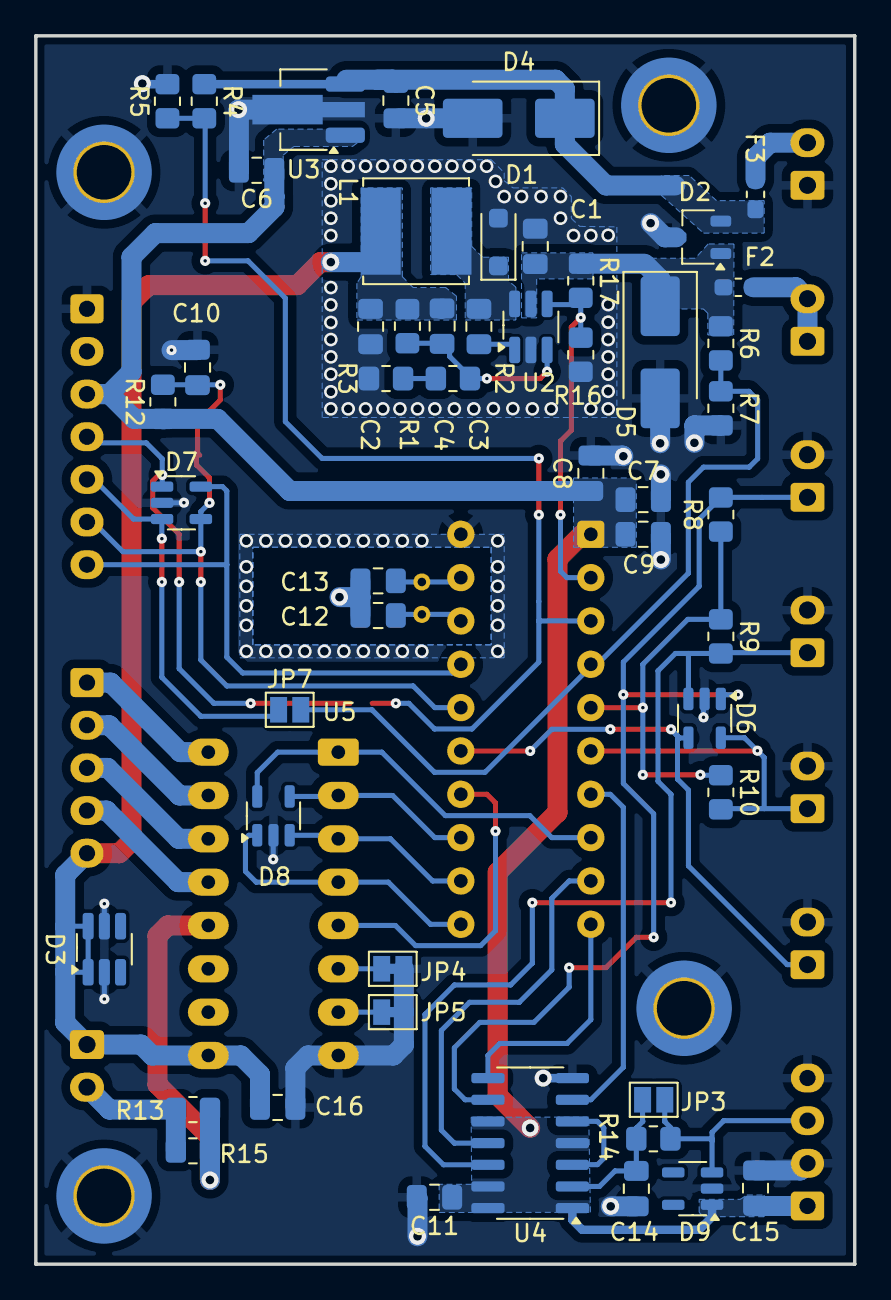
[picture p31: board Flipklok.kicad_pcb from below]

Board: 2 copper layers, 48.0 x 72.0 mm, 70 parts (51 on the bottom side), 44 nets.

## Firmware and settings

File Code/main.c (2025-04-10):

/**
 * @file main.c
 * @brief Startup of system
 */

#include <msp430.h>
#include "pins.h"
#include "gpio.h"
#include "clock.h"
#include "timer.h"
#include "adc.h"
#include "stepperAdvance.h"
#include "fwdButton.h"
#include "dcfReceive.h"
#include "led.h"
#include "timeKeeping.h"
#include "pinInterrupts.h"
#include "uart.h"

#include "storeLoadMechanicalTime.h"

#warning "project > properties > buid > MSP430 compiler > optimization > optimization level"
#warning "(set to 1 for default, 0 for acces to non global variables while in debug mode)"

// Check if the INFOD section (0x1000 - 0x0040) is NOT within the main FLASH region
#if ((0x1000 >= __INFOA__) || (0x0040 < __FLASH_START__))
    #warning ("INFOD (0x1000 - 0x0040) is safe for user data storage.")
#else
    #error "Warning: INFOD (0x1000 - 0x0040) is part of FLASH! Do NOT use for data storage."
#endif

uint32_t setTime;
uint32_t loaded_value;

/**
 * @brief Main function that initializes system components and enters low-power mode.
 *
 * This function is responsible for setting up various system components, including
 * the GPIO, ADC, clocks, and timekeeping system. It also loads the mechanical time from flash memory (if it is connected to a debugger the flash is cleared and the mechanical time must be set manually).
 * It also initializes the UART (if enabled). Additionally, the function sets the time of the
 * mechanical clock and enters low-power mode with interrupts enabled. The system performs
 * various initialization tasks to ensure the proper operation of the application.
 *
 * It performs the following steps:
 * - Stops the watchdog timer to prevent system reset.
 * - Initializes UART if `UART_ENABLED` is defined.
 * - Sets up GPIO, ADC, clocks, and timekeeping.
 * - Writes the stored mechanical time from flash to UART.
 * - If the value is invalid because the debugger overwritten the flash, enters an infinite loop.
 * - Configures timers and enters low-power mode with interrupts.
 *
 * @note If UART is enabled, a warning will be displayed that the UART will be initialized.
 */

volatile uint32_t setMinute;
void main(void)
{
	WDTCTL = WDTPW | WDTHOLD;		// stop watchdog timer
	FCTL2 = FWKEY + FSSEL0 + FN1;             // MCLK/3 for Flash Timing Generator
    #ifdef UART_ENABLED
        #warning("Warning: UART is enabled! disable define of UART_ENABLED to disable it.")
	    UART_Init();  // Initialize UART
    #endif

	setupGpio();
	setupAdc();
	setupClocks();
    resetTimeKeeping();

    //For testing, setting time of mechanical clock
    P2DIR &= ~BIT2;                             // Input
    P2REN |= BIT2;   // Enable pull-up/down resistor
    P2OUT |= BIT2;   // Select pull-up

    if ((P2IN & BIT2))
    {
        setMinute = 02;
        volatile uint32_t setHour = 20;
        setTime = setHour * 3600 + setMinute * 60;
        write_SegD(setTime);                    // Write 32-bit value to segment C, increment value
        __no_operation();
    }

    __delay_cycles(100000);
    loaded_value = load_from_flash(); // Load the value from flash
    if (loaded_value == 0xFFFFFFFF)
    {
        __delay_cycles(100000);
        __no_operation();
        while(1)
        {
            __no_operation();
        }
    }
    __delay_cycles(100000); //wait time otherwise to quick between writing and reading from flash
    mechanicalTimeFloat = loaded_value;
    timeOfLastDcfMessage = mechanicalTimeFloat; // Set the time of DCF before any message received the same as mechanical time so the clock does not stand still at startup
    #ifdef UART_ENABLED
        UART_SendString("\r\n------Starting------\r\n");
        UART_SendString("mechanicalTime: ");
        UART_SendTime(mechanicalTimeFloat);
    #endif

    setupTimer0();
    setupTimer1();

    __bis_SR_register(LPM3_bits | GIE);
}

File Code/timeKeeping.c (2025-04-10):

/*
 * timekeeping.c
 *
 *  Created on: 21 mrt. 2025
 */
/**
 * @file timeKeeping.c
 * @brief handles the keeping and calculating of time of the system
 */

#include "timeKeeping.h"
#include "dcfReceive.h"
#include "uart.h"
#include "pinInterrupts.h"

bool toggleCalculateTimeDifference = 1;

//declare it globally
uint32_t timeOfLastDcfMessage = 0;
uint32_t timeSinceLastCompleteDcfMessage = 0;
double mechanicalTimeFloat = 0;


/**
 * @brief calculate the difference between the mechanical time and the current time to have the time difference which the stepper needs to be advanced with, gets called from end interrupt of ISR_TA0(void).
 *
 * It then calculates the amount of steps that are needed to advance the clock to display the current time.
 * The function take in to account which way it is the fastest to fully wrap the clock or to wait until the time synchronizes
 */

void calculateTimeDifference()
{
    if(countDcf77Messages > 0)
    {
        __no_operation();
        volatile int testing = 0;
    }
    volatile uint32_t timeDiff;
    __no_operation();
    toggleInterruptDcf = 1; // Enable dcfReceive interrupt
//    unsigned int state = __get_SR_register() & GIE; __disable_interrupt();  // Save current interrupt state and disable interrupts
    if (0 == toggleFwdInterrupt) //fwdButton is not pressed otherwise skip time keeping
    {
        if(0 == countDcf77Messages) // When no DCF77 message has been received work only on internal clock
        {
            timeDiff = timeOfLastDcfMessage + timeSinceLastCompleteDcfMessage - mechanicalTimeFloat;
            P1DIR |= BIT7;                              // set as output enables indicator LED, indicating clock is off time
        }
        else if(countDcf77Messages > 0) // One or more DCF77 messages has been received use the time of DCF to set clock
        {
            if((timeOfLastDcfMessage + timeSinceLastCompleteDcfMessage) > mechanicalTimeFloat) // Clock runs behind need to be advanced to current time
            {
                timeDiff = (timeOfLastDcfMessage + timeSinceLastCompleteDcfMessage) - mechanicalTimeFloat; // Calculate how much the clock runs behind
            }
            else if((timeOfLastDcfMessage + timeSinceLastCompleteDcfMessage) < mechanicalTimeFloat) //Clock runs ahead
            {
                if((mechanicalTimeFloat - (timeOfLastDcfMessage + timeSinceLastCompleteDcfMessage)) > clockWraparoundThresholdSec) // When the time that the clock runs ahead is greater than the threshold than rotate to 00:00 so it can sync from there
                {
                    timeDiff = secondsInDay + 60 - mechanicalTimeFloat; // Calculate the amount of time between clock current state and the time until 00:01
                }
                else if((mechanicalTimeFloat - (timeOfLastDcfMessage + timeSinceLastCompleteDcfMessage)) <= clockWraparoundThresholdSec) // If the time that the clock runs ahead is less or equal to the threshold it is faster to just wait until the clock is on time
                {
                    timeDiff = 0;
                }
                else
                {
                    __no_operation(); //?
                }
            }
            else
            {
                __no_operation(); //?
            }
        }
        else
        {
            __no_operation(); //?
        }

        //Checking if calculated time is plausible
        if (timeDiff > secondsInDay)
        {
            __no_operation(); //Clock will rotate more than a full turn, disable stepper and recalculate
        }
        else // Calculated time is plausible convert to needed steps
        {
            if (timeDiff > 60) // If the time difference is large enough stop receiving dcf messages to prevent crosstalk between stepper and receiver, is enabled again at start of this function
            {
                toggleInterruptDcf = 0; // Disable dcfReceive interrupt until clock is done syncing
                P1DIR |= BIT7;                              // set as output enables indicator LED, indicating clock is off time
                toggleFwdInterruptISR = 0; // Disable fwdButton when calculating time and adjusting the clock (enabled again in stepperAdvance function)
                timerCompareStepperSpeedToggle = 1; //set stepper speed to fast
            }
            else
            {
                timerCompareStepperSpeedToggle = 0; //set stepper speed to slow
                if (0 < countDcf77Messages)
                {
                    P1DIR &= ~BIT7;                              // set as input disables indicator LED, indicating clock runs on time
                }
            }
            stepsRemaining = calculateStepsToTake(timeDiff);
//            #ifdef UART_ENABLED
//                UART_SendInt(timeDiff);
//            #endif
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

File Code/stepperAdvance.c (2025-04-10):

/**
 * @file stepperAdvance.c
 * @brief Setup and control of stepper motor
 */

#include "stepperAdvance.h"
#include "timeKeeping.h"
#include "uart.h"
#include "storeLoadMechanicalTime.h"
#include "pinInterrupts.h"

/**
 * @brief Advances the stepper each time it gets called by one full step gets triggered by ISR_TA0().
 *
 * Step sequence:
 *  - 0001
 *  - 0010
 *  - 0100
 *  - 1000
 * @return void
 */
int stepperArray[] = {BIT0, BIT3, BIT4, BIT5};
void stepperAdvance()
{
    if (P1IN & BIT0) // if 5V converter is on turn stepper
    {
        toggleCalculateTimeDifference = 0;          // disable triggering time difference function in timer interrupt.
        static unsigned int coil;
        if (stepsRemaining > 0 || toggleFwdInterrupt == 1)
        {
            P2OUT &= ~(STEPPER1 + STEPPER2 + STEPPER3 + STEPPER4);
            P2OUT |= stepperArray[coil];
            if (coil == 3)
            {
                P2OUT |= stepperArray[0];
            }
            else
            {
                P2OUT |= stepperArray[coil + 1];
            }

            coil++;
            if (coil == 4)
            {
                P2OUT |= stepperArray[0];
                coil = 0;
            }


            if (toggleFwdInterrupt == 0)
            {
                stepsRemaining--;
                mechanicalTimeFloat = mechanicalTimeFloat + timePerStep; //Increment mechanical time keeping counter with 1 step time

                if(mechanicalTimeFloat > 86400)
                {
                    mechanicalTimeFloat = 0; //reset after 24:00
                    #ifdef UART_ENABLED
                        UART_SendString("mechTime reset\r\n");
                    #endif
                }

                if((stepsRemaining > 999) && (0 == (stepsRemaining % 1000))) //every 1000 steps print steps remaining
                {
                    #ifdef UART_ENABLED
                        UART_SendString("s: ");
                        UART_SendUint32(stepsRemaining);
                        UART_SendString(", MTC: ");
                        UART_SendTime(mechanicalTimeFloat);
                        UART_SendString("\r\n");
                    #endif
                }
            }
        }
        else
        {
            TA0CCTL2 &= ~CCIE;                          // TACCR2 interrupt stepperAdvance disable
//            storeTime((uint32_t)mechanicalTimeFloat); // Store the current state of the clock in non volatile flash
            write_SegD((uint32_t)mechanicalTimeFloat);
            toggleCalculateTimeDifference = 1;          // enable triggering time difference function in timer interrupt.
            toggleFwdInterruptISR = 1;                     // Enable fwdButton interrupt again (disabled in timekeeping function when it is syncing)
        }
    }
}

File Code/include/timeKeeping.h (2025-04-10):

/*
 * calculateTimeDifference.h
 *
 *  Created on: 21 mrt. 2025

 */

#ifndef CALCULATETIMEDIFFERENCE_H_
#define CALCULATETIMEDIFFERENCE_H_
#include <msp430.h>
#include <stdbool.h>
#include <stdint.h>  // Include to define uint32_t

extern bool toggleCalculateTimeDifference;

void calculateTimeDifference();
uint32_t calculateStepsToTake();
void storeTimeLastCompleteDcfMessage();
void resetTimeKeeping();

extern uint32_t timeOfLastDcfMessage;
extern uint32_t timeSinceLastCompleteDcfMessage;
#define timerCountsInDay 60 * 60 * 24 / (capacityTimer / clockFreq)

#define toothGearStepper 15.0
#define toothGearClock 24.0
#define gearRatio (toothGearClock / toothGearStepper)
#define stepsFullRotationStepper 2048.0
#define stepsClockHour (stepsFullRotationStepper * gearRatio)
#define stepsClockMinute (stepsClockHour / 60.0)
#define stepsClockSecond (stepsClockMinute / 60.0)
#define timePerStep (3600.0 / (stepsFullRotationStepper * gearRatio))
#define stepsToggleThreshold 20
#define clockWraparoundThresholdSec (10 * 60)
#define stepsWrap (stepsClockHour * 24)
#define secondsInDay 86400
#define stepsInDay (stepsClockSecond * secondsInDay)

//Needs to be stored in non volatile storage (FRAM), to be persistent across boot
extern double mechanicalTimeFloat; //time of mechanical clock mechanism should be in double/floating point
//uint32_t mechanicalTimeInt; //Integer display of floatingpoint timeMechanical

uint32_t stepsRemaining;


volatile bool toggleTimer1Direction; // 1 is up 0 is down


#endif /* CALCULATETIMEDIFFERENCE_H_ */

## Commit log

2025-03-10 Started working on mechanics mounting the stepper motor
    [28byj-48 5v stepper motor.SLDPRT, Alarmwheel.SLDPRT, clockAssembly.SLDASM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]
2025-03-10 Added influxDB support to log errors
    [main.cpp]
2025-03-10 Started working on motor holder v2
    [Alarmwheel.SLDPRT, clockAssembly.SLDASM, clockGear-1M-24T.SLDASM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]
2025-03-11 Initial schematic commit Started working on schematic
    [Flipklok.kicad_pcb, Flipklok.kicad_sch]
2025-03-11 Revert "Initial schematic commit Started working on schematic"
    This reverts commit 41658e12fd88ed23b74b87337d35702dc5f5711a.
    [Flipklok.kicad_pcb, Flipklok.kicad_sch]
2025-03-12 Finished REV1.0 of schematic, started working on PCB
    [Flipklok.kicad_pcb, Flipklok.kicad_sch]
2025-03-13 Started optimizing routing and layout
    [Flipklok.kicad_pcb, Flipklok.kicad_sch]
2025-03-14 Finished lay-out and exported gerbers
    [Flipklok.kicad_pcb, Flipklok.kicad_sch, bom.csv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]
2025-03-14 Finished drawing the gears and including them in the main assembly
    [clockGear-1M-24T.SLDASM, motorGear-1M-15T.SLDASM, motorGear-1M-22T.SLDASM]
2025-03-17 exported plots of pcb and schematic
    [Flipklok.kicad_pcb, Flipklok.kicad_sch]
2025-03-17 Started design on case
    [Connector GX16 DCF77.SLDPRT, Flipklok-pcb.SLDASM, Flipklok-pcb.step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]
2025-03-18 Finished case
    [LED-plug.SLDPRT, case-backpanel.SLDPRT, case.SLDPRT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]
2025-03-18 added step file and needed symbol lib
    Step file contains PCB including 3d components
    Added the custom symbol library for the components: AP2205-33YR-13, AP5100W, ESDA19C6
    [Flipklok.step]
2025-03-19 Visualized the influxdb data
    [InfluxDB data visualized.ods]
2025-03-20 added stepper motor and fwdButton function
2025-03-21 added ADC and led/ldr control
2025-03-21 editted screw and insert dimensions based on testing
    [case-backpanel.SLDPRT, case.SLDPRT, clockGear-1M-24T.SLDASM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]
2025-03-25 generated interactive BOM for assembly
2025-03-25 filled in "to be detriment values" and updated BOM
    [Flipklok.kicad_pcb, Flipklok.kicad_sch]
2025-03-25 filled in led resistor
    [Flipklok.kicad_pcb]
2025-03-27 Finished rewriting for new devboard and PCB
2025-03-28 Finished DCF emulator
    added epoch test to constantly 'send' out unix epoch time and a function to 'send' the current NTP time
2025-03-31 fixed timing and added sync bit
    code now implements sync bit between dcf77 messages according to https://wolles-elektronikkiste.de/en/dcf77-radio-controlled-clock
    This help receivers sync with the dcf77 messages, to now when a message starts and ends
    [main.cpp]
2025-04-03 added offset filter and changed to esp32
2025-04-03 Time keeping works
    A broken clock is right twice a day, but a working clock is much nicer
    [main.c, stepperAdvance.c, timeKeeping.c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]
2025-04-04 fixed: adc, fwdButtton, indicatorLed,
    Fixed adc readings
    Fwd button only works when the clock is not syncing
    And the indicator led shows if the clock is on time (off) or off time (on), the brightness is controlled by the LDR
    [adc.c, dcfReceive.c, gpio.c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]
2025-04-07 Revision 2 of backplate
    Moved the PCB more to the side on the backplate to make room for new stepdown converter PCB
    [case-backpanel.SLDPRT, clockGear-1M-24T.SLDASM, motorGear-1M-15T.SLDASM]
2025-04-07 Rewritten timekeeping, added checks, added 5v enable
2025-04-09 Finished working on lowpower settings and rewritten flash
    Flash storage works when debugger is not connected. The debugger overwrites the flash this causes the mechanical time to be not kept across reboots/debug-sessions
    [adc.c, dcfReceive.c, gpio.c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]
2025-04-10 updated doc added bill of material
2025-04-10 updated doxy, added readme and bom as pages
2025-04-10 removed export folder
    [motorHolder-rev-1.3MF]
2025-04-10 removed export mechanics
    [motorHolder-rev-1.3MF]
2025-04-10 fix adc, add uart bitstream, added blinking light when out of sync
    [adc.c, dcfReceive.c, led.c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]
2025-04-10 fixed integer overflow and added button check before setting time on startup
    [adc.c, dcfReceive.c, gpio.c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]
2025-04-15 Updated the docs to include the DCF77 data
    [error-data.csv, error-data.ods]
